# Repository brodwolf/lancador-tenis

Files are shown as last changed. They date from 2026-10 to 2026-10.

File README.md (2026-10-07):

# Lançador de Bolas de Tênis

Máquina de treino portátil, montada em três andares que se separam. Tem duas rodas de velocidade independente para controlar o spin, cabeça com giro e inclinação motorizados, cesto de tela dobrável e baterias Makita 18 V. Projeto aberto, pensado para ser construído com impressão 3D, corte a laser e peças de prateleira.

**Apresentação do projeto:** https://brodwolf.github.io/lancador-tenis/

Demonstração do site

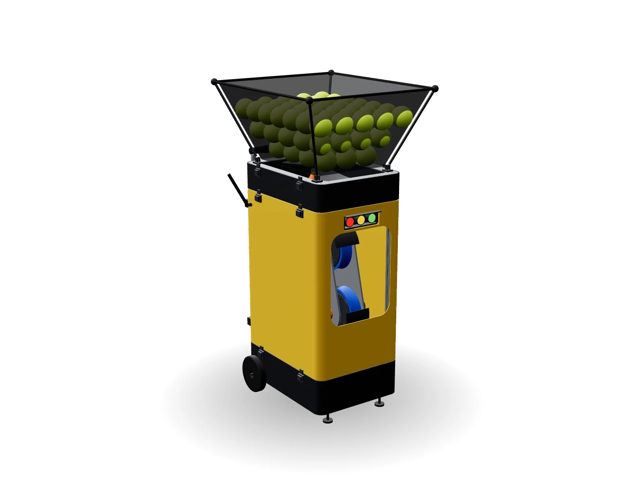
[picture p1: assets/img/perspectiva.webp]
Montagem completa


| Especificação | Valor |
| --- | --- |
| Velocidade da bola | 30–120 km/h |
| Spin | −2.500 rpm (slice) a +3.000 rpm (topspin) |
| Giro / inclinação | ±12,5° / 0° a +30° (máquina no centro da linha de fundo) |
| Cesto | Tela dobrável, ~120 bolas |
| Autonomia | 2,3–4,5 h com 2 baterias Makita 5,0 Ah |
| Dimensões | 32 × 43 cm de base; ~82 cm de altura com o cesto dobrado, 104,5 cm aberto; ~20 kg sem carenagem |
| Carenagem | Material a definir; só STEP de referência |
| Custo estimado | R$ 4,6–8,1 mil, sem baterias e sem carenagem |

## O que tem aqui

| Pasta | Conteúdo |
| --- | --- |
| `index.html`, `assets/` | Página de apresentação: modelo 3D interativo (com e sem carenagem) e simulação na quadra com vento (GitHub Pages) |
| `PROJETO.md` | Memorial técnico em Markdown (sem preços e sem próximos passos) |
| `cad/montagem/` | Montagem em STEP com e sem carenagem (Fusion 360, FreeCAD, Onshape, SolidWorks) |
| `cad/impressao_3d/` | STL e STEP das peças impressas (as `_espelhada` são a cópia do outro lado) |
| `cad/corte_laser/` | DXF das 10 chapas (mm, 1:1) e pranchas em PDF |
| `cad/carenagem/` | STEP dos painéis externos, material a definir |
| `cad/usinagem/` | Eixos em STEP |
| `cad/lista_de_pecas.csv` | Todas as peças com categoria, material e quantidade |
| `cad/lancador.py` | Modelo paramétrico em CadQuery |

A versão anterior, uma estrutura única de 55 × 45 × 120 cm, está no branch [`v1`](../../tree/v1).

## Gerar os arquivos de novo

```
pip install cadquery ezdxf matplotlib
cd cad
python3 exportar.py      # recria STEP, STL, DXF, GLB e a lista de peças em cad/saida/
python3 verificar.py     # confere folgas em 18 posições de giro e inclinação, o caminho da bola e todas as peças entre si
```

Os parâmetros principais ficam no topo de `cad/lancador.py`: tamanho da carenagem, alturas dos andares, linha da bola, rodas e vão, motores e faixas de giro e inclinação.

## Antes de mandar cortar

Os furos de peças compradas seguem cotas de catálogo. Confira com a peça na mão:

- KFL001: 48 mm entre furos, M6
- KFL08: 37 mm entre furos, M4
- lazy susan Ø150: a furação varia por fabricante
- X-mount do motor 4250

Detalhes em `cad/LEIAME.md`.

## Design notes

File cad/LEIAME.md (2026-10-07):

# Lançador de bolas de tênis, versão 2 (compacta, por andares)

Modelo paramétrico feito em CadQuery (Python). Unidades em milímetros.
Origem no chão, no centro da máquina: **x** = largura, **y** = profundidade (+ para a frente), **z** = altura.

A máquina tem três andares que se encaixam com pinos de centragem e travam com fechos de pressão.

- **Controle:** baterias, caixa IP65 e rodas de transporte.
- **Lançador:** giro, inclinação, cabeça, painel traseiro, semáforo e antenas.
- **Alimentador:** disco agitador e rampas.

O cesto de tela dobrável vai por cima dos três.

## Pastas

| Pasta | O que tem | Para quem |
| --- | --- | --- |
| `montagem/lancador_montagem.step` | Montagem completa **com** carenagem | Ver como fica (Fusion 360, FreeCAD, Onshape, SolidWorks) |
| `montagem/lancador_montagem_sem_carenagem.step` | Mesma montagem **sem** carenagem | Montar e conferir a estrutura |
| `corte_laser/` | DXF 1:1 em mm de cada chapa + `pranchas_corte_laser.pdf` com cotas gerais | Serviço de corte a laser |
| `impressao_3d/` | STL (fatiador) e STEP (editar) de cada peça impressa | Sua impressora |
| `usinagem/` | STEP dos eixos | Torno ou barra cortada em casa |
| `carenagem/` | STEP dos painéis externos | Quem for fazer o molde ou os painéis |
| `visualizador/` | GLB da montagem + `pecas.json` (usados pelo site) | Conferir a montagem |
| `lista_de_pecas.csv` | Todas as peças com categoria, material, quantidade e arquivo | Planilha de compras |
| `lancador.py`, `exportar.py`, `verificar.py` | Código-fonte | Mudar cotas e gerar tudo de novo |

## Carenagem: material a definir

A carenagem tem três painéis (um por andar) e a tampa das baterias. **Ela não tem DXF**, porque ainda não se sabe se será molde injetado, termoformada, impressa em partes ou chapa composta.

Os STEP têm 3 mm de parede, cantos de raio 30 e todos os recortes:

- janela da cabeça, semáforo, painel traseiro
- furos das antenas e dos eixos das rodas
- rasgos das abraçadeiras da alça

Servem de base para o molde ou para refazer os painéis no material escolhido. A estrutura não depende da carenagem: a máquina funciona sem ela.

## Antes de mandar cortar as chapas

Os furos de peças compradas seguem cotas de catálogo. **Confira com a peça na mão** antes de enviar os DXF:

- **KFL001** (mancais das rodas): 2 furos M6 a 48 mm. Na placa lateral os furos são de Ø7. A roda de baixo usa furos oblongos, para ajustar o vão.
- **KFL08** (mancais do tilt): 2 furos M4 a 37 mm. No garfo os furos são de Ø4,5.
- **Rolamento lazy susan redondo Ø150**:
  - a furação varia por fabricante; ajuste no `lancador.py` ou fure na montagem
  - base do andar: 4 furos a r 66, girados 45°
  - plataforma: 4 furos a r 60
- **Motor 4250 (X-mount)**: 4 oblongos M3 a r 19, alinhados com a correia, que dão ±3 mm para esticar.
- **Correias**: HTD 3M de 9 mm, fechadas.
  - roda de cima: **600-3M-9**
  - roda de baixo: **288-3M-9**
  - a posição dos motores sai do comprimento da correia; se mudar a correia, mude `CORREIA_A`/`CORREIA_B`
- **NEMA17**: furação padrão de 31 mm, M3.
- **Disco de inércia**: furo em D para o eixo Ø12 com chato (11,1 mm entre a face plana e o lado oposto).
- **Manivela do tilt**: furo em D para o semi-eixo Ø8 com chato de 7 mm.

O laser não faz rosca: rosqueie em casa os furos indicados no documento do projeto.

## Imprimindo

- As peças saem na **posição de montagem**: gire na mesa do fatiador para a melhor orientação.
- Use PETG em tudo, menos a banda das rodas (TPU 95A). Peças expostas ao sol podem ser em ASA.
- `nucleo_roda`: 6 perímetros, 60% gyroid. `banda_roda`: 4 perímetros, 50% gyroid, 20–30 mm/s.
- `rotor_agitador` tem Ø220 mm: cabe em mesa de 235 mm.
- As rampas do alimentador vêm em 4 partes. As duas da frente têm 155 × 256 mm: precisam de mesa de 256 mm ou de um corte a mais.
- Arquivos com `_espelhada` no nome são a cópia do outro lado. Por exemplo, a abraçadeira da alça e o suporte da antena do lado esquerdo.

## Movimentos

| Eixo | Faixa | Acionamento |
| --- | --- | --- |
| Giro (pan) | ±12,5° | NEMA17 com fuso Tr8×8 de 100 mm empurrando um pino a 102 mm do eixo |
| Inclinação (tilt) | 0° a +30° | NEMA17 com fuso Tr8×2 de 100 mm (não volta sozinho), porca com rasgo e manivela de 64 mm |
| Rodas | 2 motores 4250 | Correias HTD 3M, polias de 20 dentes (1:1) |

## Gerar de novo depois de mudar cotas

```
pip install cadquery ezdxf matplotlib
python3 exportar.py      # recria a pasta saida/
python3 verificar.py     # confere as folgas em 18 posições de giro e inclinação e o caminho da bola
```

Os parâmetros principais estão no topo de `lancador.py`: tamanho da carenagem, alturas dos andares, altura da linha da bola, rodas e vão, posição dos motores e faixas de giro e inclinação.

## Simplificações do modelo

São representações simples:

- parafusos, fiação e placas eletrônicas
- servo, tela e baterias
- tela do cesto

Rolamentos e motores têm só as dimensões externas. O fuso dos NEMA17 aparece como uma barra lisa.

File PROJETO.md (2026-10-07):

# Lançador de Bolas de Tênis — Projeto Detalhado

Revisão de 6 de outubro de 2026 · [apresentação com o modelo 3D](https://brodwolf.github.io/lancador-tenis/) · [repositório](https://github.com/brodwolf/lancador-tenis). Esta versão traz o memorial técnico completo; preços, custos e próximos passos ficam de fora.

## 1. Visão geral e decisões de projeto

A v2 tem um objetivo: portabilidade. A máquina ficou no menor tamanho possível (32 × 43 cm de base, ~82 cm de altura com o cesto dobrado), montada em três andares empilhados que se separam sem ferramenta.

Ela trabalha sempre no centro da linha de fundo: dali, ±10° de giro cobrem os cantos do fundo e ±12,5° os da área de saque. A ideia central continua: **só a "cabeça" se move**, e a bola desce por um tubo fixo sobre o eixo do giro. Não mudaram: duas rodas Ø150 independentes com sensor Hall, ESP32‑S3, baterias Makita com diodos ideais, disco agitador e empurrador a servo.

| # | Na v1 | Na v2 | Por quê |
| --- | --- | --- | --- |
| 1 | Uma estrutura alta com os níveis presos nela | Três andares empilhados, centrados por pinos e travados por fechos de pressão | Encolhe e se separa em partes para levar no carro |
| 2 | Perfil 30×30, ~11 m | Perfil 20×20 em cada andar, ~4,1 m | Andares baixos e chapas grossas dão a rigidez; perfis com ~1 kg em vez de 6–9 kg |
| 3 | Giro ±30° | ±12,5° | Basta para a máquina no centro da linha de fundo; menos espaço em volta da cabeça |
| 4 | Inclinação −15° a +15° | 0° a +30° | Lobs e bolas lentas; com a máquina no fundo, ângulo negativo não serve |
| 5 | Linha da bola a 720 mm | 381 mm | Máquina baixa; a altura de saída muda a inclinação necessária só +1 a 2,5° |
| 6 | Motor no eixo da roda, por fora das placas | Correias HTD 3M (1:1), motores entre as placas | Cabeça com 156 mm de largura; a correia isola o motor do choque do disparo |
| 7 | Hopper rígido, 80–100 bolas | Cesto de tela dobrável, ~120 bolas | Dobrado, a altura de transporte cai para ~815 mm |
| 8 | Lazy susan de 300 mm | Lazy susan redondo Ø150 | Giro pequeno e cabeça estreita; cabe na base |
| 9 | Giro por correia GT2 num aro de Ø300 | Fuso Tr8 empurrando um pino a 102 mm do eixo | Sem aro grande; resolução de ~0,0014° |
| 10 | Chave geral náutica; controle só pelo celular | Painel traseiro (tela touch, emergência, liga/desliga com chave anti-faísca), semáforo na frente, antenas de 433 MHz e Wi‑Fi | Usa sem celular; quem está na quadra vê a próxima bola e pausa pelo controle remoto |
| 11 | Telas perfuradas | Carenagem como conjunto separado, material a definir (talvez plástico injetado), só em STEP | A estrutura funciona sem ela; o material decide processo e custo |

Este memorial define dimensões, componentes, ligações e firmware. Os arquivos de CAD (STEP, STL e DXF) seguem estas cotas e estão em [Arquivos do projeto](#arquivos).

## 2. Especificações-alvo

A máquina lança de 30 a 120 km/h com até 3.000 rpm de spin, cobrindo aquecimento, drives, topspin, slice, lobs e bolas rápidas.

| Parâmetro | Alvo | Observação |
| --- | --- | --- |
| Velocidade da bola | 30–120 km/h | Calibrada por fator de eficiência no firmware |
| Spin | −2.500 rpm (slice) a +3.000 rpm (topspin) | Diferença de velocidade entre as rodas |
| RPM máxima da roda | 5.500 rpm | Limite de projeto (roda Ø150 mm) |
| Cadência | 1 bola a cada 1,5–10 s | Só dispara quando as duas rodas estão na RPM alvo |
| Giro horizontal (pan) | ±12,5° | Resolução de ~0,0014° |
| Inclinação (tilt) | 0° a +30° | Resolução de ~0,0006° |
| Altura de lançamento | 381 mm | Igual em qualquer inclinação (o pivô fica na linha da bola) |
| Capacidade do cesto | ~120 bolas | Cesto de tela dobrável, ~40 L |
| Alimentação | 2× Makita 18 V LXT, hot swap | Entrada AC opcional (fase 2) |
| Autonomia | 2,3–4,5 h com 2× 5,0 Ah | Ver cálculo na seção 3 |
| Dimensões em uso | 37,4 × 43 × 104,5 cm | Com as rodas; cesto aberto |
| Dimensões de transporte | 37,4 × ~45,5 × ~81,5 cm | Cesto dobrado, alça recolhida |
| Peso | ~20 kg sem carenagem e sem bolas | Carenagem em ABS: +~3 kg; 120 bolas: ~6,9 kg |
| Controle | Celular (Wi‑Fi), tela touch e controle remoto 433 MHz | Botão de emergência físico |

## 3. Física e dimensionamento

Com rodas de Ø150 mm, a bola mais exigente (110 km/h com 3.000 rpm de topspin) pede 5.443 rpm na roda de cima, por isso o limite de projeto é 5.500 rpm.

### 3.1 Velocidade e spin

A bola sai com a média das velocidades periféricas das rodas, menos as perdas por compressão e escorregamento. O spin vem da diferença entre as rodas.

```math
v_{bola} \approx \eta \cdot \frac{v_{sup} + v_{inf}}{2} \qquad \omega_{bola} \approx k \cdot \frac{v_{sup} - v_{inf}}{g}
```

Para o firmware, a conta é invertida (o usuário escolhe velocidade e spin, a máquina calcula as RPMs):

```math
v_{sup,inf} = \frac{v_{bola}}{\eta} \pm \frac{\omega_{bola} \cdot g}{2k} \qquad RPM = \frac{60 \cdot v_{roda}}{\pi \cdot D_{roda}}
```

Onde g = vão entre as rodas (56 mm), D = diâmetro da roda (150 mm), η ≈ 0,90 e k ≈ 1,0 são fatores de calibração ajustados na prática. Spin positivo = topspin (roda de cima mais rápida).

| Tipo de bola | Velocidade (km/h) | Spin (rpm) | Roda superior (rpm) | Roda inferior (rpm) |
| --- | --- | --- | --- | --- |
| Aquecimento | 40 | 0 | 1.572 | 1.572 |
| Voleio | 60 | 0 | 2.358 | 2.358 |
| Slice | 70 | −1.500 | 2.191 | 3.310 |
| Drive plano | 80 | 0 | 3.143 | 3.143 |
| Topspin médio | 80 | +1.500 | 3.704 | 2.583 |
| Topspin pesado | 90 | +2.500 | 4.470 | 2.604 |
| Bola rápida plana | 120 | 0 | 4.716 | 4.716 |
| Limite de projeto | 110 | +3.000 | 5.443 | 3.203 |

### 3.2 Inércia da roda e consistência

A bola a 120 km/h leva ~32 J de energia cinética (m = 57,5 g). Cada roda cede ~15–25 J por disparo, contando as perdas.

Cada roda tem I ≈ 2,6 × 10⁻³ kg·m² (núcleo impresso + 2 discos de aço + banda de TPU, ~1 kg; a polia soma pouco). A 3.500 rpm ela guarda ~175 J, então cai só 5–7% de RPM por disparo. O firmware espera a RPM voltar (< 0,5 s) antes do próximo disparo.

### 3.3 Motores e correias

- **KV:** para chegar a 5.500 rpm com carga e bateria no fim (16 V), KV ≥ 5.500 / (0,85 × 16) ≈ 400. Faixa recomendada: **400–500 KV**.
- **Torque de partida:** acelerar de 0 a 3.500 rpm em 5 s exige ~0,19 N·m (~9 A por motor). Rampas mais rápidas somam corrente; o firmware limita a rampa para manter o total abaixo de 25 A.
- **Recuperação:** repor 20 J em 0,5 s = ~40 W por motor, uma fração da capacidade.
- **Classe:** outrunner 4250 (Ø42 × 50 mm), ≥ 500 W: é o tamanho que cabe entre as placas. A potência média é baixa; a folga é térmica e de durabilidade.
- **Transmissão:** correia HTD 3M 1:1 (RPM do motor = RPM da roda). Ela só leva o torque do motor (~0,2–0,4 N·m na aceleração); o choque do disparo fica com a inércia da roda e os mancais.

### 3.4 Autonomia

Uma Makita 18 V 5,0 Ah tem 90 Wh, dos quais ~80 Wh são úteis até 15 V. Duas baterias dão ~160 Wh.

| Situação | Consumo médio | Autonomia (2× 5,0 Ah) |
| --- | --- | --- |
| Rodas girando, sem disparar | ~25 W | ~6 h |
| Treino típico (80 km/h, 1 bola a cada 4 s) | ~35–45 W | ~3,5–4,5 h |
| Treino pesado (120 km/h, 1 bola a cada 2 s) | ~60–70 W | ~2,3–2,7 h |

São estimativas. O firmware mede a tensão de cada bateria; com um sensor de corrente opcional (INA226) você mede o consumo real.

### 3.5 Trajetória e simulação na quadra

A aba **Quadra**, ao lado do modelo 3D, mostra onde a bola quica. A máquina fica no centro, com a frente da carenagem encostada na linha de fundo (ou na linha de saque), e a bola sai logo depois do ponto de contato das rodas, a ~0,38 m do chão com a cabeça a 0° (~0,51 m a +30°), na direção dada pelo giro e pela inclinação. Também dá para tocar num ponto da quadra adversária: a página calcula o giro e a inclinação para a bola quicar ali. Há ainda vento, com velocidade de 0 a 40 km/h e direção; com a mira ativa, a página corrige giro e inclinação para compensar.

[Abrir a simulação na quadra](https://brodwolf.github.io/lancador-tenis/#quadra)

Em voo, a bola sofre o peso, o arrasto do ar e a força de Magnus causada pelo spin. As duas forças do ar dependem da velocidade da bola **em relação ao ar**, v_r = v − v_vento:

```math
m\,\frac{d\vec v}{dt} = m\,\vec g \;-\; \tfrac{1}{2}\,\rho A\,C_D\,|\vec v_r|\,\vec v_r \;+\; \tfrac{1}{2}\,\rho A\,C_L\,|\vec v_r|^2\,(\hat\omega \times \hat v_r) \qquad \vec v_r = \vec v - \vec v_{vento}
```

Os coeficientes vêm do ajuste empírico de Goodwill, Chin e Haake (2004), medido em túnel de vento com bolas girando, em função da razão entre a velocidade da bola em relação ao ar, v, e a velocidade periférica do spin, v_s = r·ω:

```math
C_D = 0{,}55 + \frac{1}{\left[\,22{,}5 + 4{,}2\,(v/v_s)^{2{,}5}\right]^{0{,}4}} \qquad C_L = \frac{1}{2 + v/v_s}
```

No quique, a velocidade vertical volta multiplicada pelo coeficiente de restituição e, e o atrito freia o ponto de contato até a bola parar de escorregar e começar a rolar (modelo de R. Cross). O mesmo atrito muda o spin: o topspin sai do quique mais rápido para a frente, e o slice freia e fica baixo.

```math
v_y' = -e\,v_y \qquad J_t = \min\!\left(\mu\,(1+e)\,|v_y|,\; \frac{\alpha}{1+\alpha}\,|u_c|\right) \qquad I = \alpha\, m\, r^2
```

Onde u_c é a velocidade do ponto de contato com o chão e J_t é o impulso de atrito por unidade de massa. A trajetória é integrada por Runge‑Kutta de 4ª ordem com passo de 2 ms.

| Parâmetro | Valor usado |
| --- | --- |
| Bola | 57 g, Ø67 mm, α = 0,55 |
| Ar | ρ = 1,21 kg/m³ (nível do mar, 20 °C); vento opcional de 0 a 40 km/h, em qualquer direção, uniforme |
| Quadra rápida | e = 0,78, μ = 0,65 |
| Saibro | e = 0,80, μ = 0,80 |
| Rede | 0,914 m no centro, 1,07 m nos postes |
| Bola dentro | 1º quique na quadra de simples do adversário; a linha conta como dentro |

Inclinação que põe o 1º quique dentro e onde ele cai (distância depois da rede), em quadra rápida, com a máquina no centro e inclinação de 0° a +30°:

| Bola | Velocidade e spin | Da linha de saque | Da linha de fundo |
| --- | --- | --- | --- |
| Aquecimento | 40 km/h, sem spin | +22° a +30° → 2,2–3,6 m | não cai dentro |
| Voleio | 60 km/h, sem spin | +11,9° a +27,7° → 4,9–11,9 m | +17,7° a +30° → 2,5–7,0 m |
| Drive plano | 80 km/h, sem spin | +8,8° a +12,9° → 8,0–11,8 m | +10,8° a +20,3° → 4,4–11,9 m |
| Topspin médio | 80 km/h, +1.500 rpm | +10° a +18° → 6,3–11,8 m | +13,4° a +30° → 3,4–11,6 m |
| Slice | 70 km/h, −1.500 rpm | +8,9° a +15,6° → 7,1–11,9 m | +11,5° a +30° → 3,7–11,6 m |
| Topspin pesado | 90 km/h, +2.500 rpm | +9,5° a +15,8° → 6,9–11,9 m | +12,3° a +25,4° → 3,8–11,8 m |
| Bola rápida plana | 120 km/h, sem spin | não cai dentro | +6,2° a +7,8° → 8,9–11,9 m |

**O que isso diz sobre o projeto:** da linha de fundo, onde a máquina fica, a faixa de 0° a +30° põe drive, topspin e slice em qualquer profundidade, de ~3,5–4,5 m da rede até a linha de fundo. O voleio de 60 km/h chega a ~7 m da rede e a bola rápida de 120 km/h só cai no fundo (~9–12 m). O aquecimento a 40 km/h não chega à quadra adversária saindo da linha de fundo: para ele, ponha a máquina na linha de saque. "Não cai dentro" quer dizer que, naquela posição, a bola ou bate na rede ou sai longa.

Quanto o vento desloca o quique: máquina na linha de fundo, inclinação ajustada para a bola quicar a 8 m da rede sem vento; "da esquerda" é o vento que vem da esquerda de quem está atrás da máquina.

| Bola | Inclinação | 10 km/h a favor | 10 km/h contra | 10 km/h da esquerda | 20 km/h a favor | 20 km/h contra | 20 km/h da esquerda |
| --- | --- | --- | --- | --- | --- | --- | --- |
| Drive plano (80 km/h, sem spin) | +14,9° | 9,2 m | 6,8 m | 0,6 m para a direita | 10,3 m | 5,5 m | 1,3 m para a direita |
| Topspin médio (80 km/h, +1.500 rpm) | +21° | 9,9 m | 6,2 m | 0,9 m para a direita | 11,9 m | 4,4 m | 1,8 m para a direita |
| Slice (70 km/h, −1.500 rpm) | +18,6° | 9,1 m | 6,6 m | 1,0 m para a direita | 10,0 m | 5,0 m | 2,1 m para a direita |

Um vento de 20 km/h contra encurta o topspin médio de 8 m para 4,4 m da rede; a favor, alonga para 11,9 m. De lado, os mesmos 20 km/h desviam a bola 1,3–2,1 m; o slice, mais lento e mais tempo no ar, é o que mais deriva.

São aproximações. Bola gasta, altitude (em São Paulo o ar é ~7% menos denso, e a bola vai um pouco mais longe), rajadas (o simulador usa vento constante e igual em toda a quadra) e os valores reais de η e k mudam o quique em alguns decímetros. A calibração do protótipo (seção 19) acerta os números.

## 4. Arquitetura e cotas

A linha da bola fica a 381 mm do chão, e o pivô do tilt fica nela, exatamente sobre o eixo do giro, 116 mm atrás do centro da máquina.

Vista lateral esquemática com as cotas de altura

Como o recuo do disparo age ao longo da linha da bola, e essa linha cruza os dois eixos, o tiro não gera torque que desvie a mira. O tubo de queda fica parado enquanto a cabeça gira e inclina embaixo dele.

**Referência de cotas:** z = altura a partir do chão; x = largura (0 no centro); y = profundidade (positivo para a frente, 0 no centro). Na cabeça: u = para a frente ao longo da linha da bola, v = para cima, origem no pivô.

- **Eixo do giro:** x = 0, y = −116 mm. Sobre ele ficam o furo de saída, o tubo de queda (z 466–696) e o pivô do tilt (z 381, 205 mm acima da plataforma).
- **Nip:** 215 mm à frente do pivô, na linha da bola.

## 5. Estrutura em andares

Três andares de chapa de alumínio e perfil 20×20 canal 6, empilhados e centrados por pinos; todas as chapas internas medem 312 × 422 mm.

### 5.1 Andares

| Andar | Base | Postes 20×20 | Topo | O que leva |
| --- | --- | --- | --- | --- |
| Controle | Piso Al 3 mm em z = 45 | 4 × 112 mm | z = 160 | Baterias, eletrônica, rodas de transporte, pés |
| Lançador | Al 4 mm em z = 160 | 4 × 536 mm + quadro do topo | z = 700 | Giro, garfo, cabeça, atuadores, painel traseiro, semáforo, antenas, alça |
| Alimentador | Al 3 mm em z = 700 | 4 × 79 mm | Aro Al 3 mm em z = 785 | Disco agitador, rampas, tubo de queda |
| Cesto | Aro do alimentador | 4 varetas Ø8 | z = 1.045 (dobrado ~815) | ~120 bolas |

### 5.2 Lista de corte (perfil 20×20 canal 6)

| Peça | Qtd | Comprimento (mm) |
| --- | --- | --- |
| Poste do andar de controle | 4 | 112 |
| Poste do andar do lançador | 4 | 536 |
| Poste do alimentador | 4 | 79 |
| Travessa lateral do quadro do topo | 2 | 360 |
| Travessa frente/trás do quadro do topo | 2 | 250 |
| **Total** | **16** | **~4,1 m** |

Peça os cortes no esquadro (±0,3 mm) e rosqueie M5 o furo central nas duas pontas de cada poste.

### 5.3 Chapas e fixação

- **Postes:** centros a ±135 mm (x) e ±190 mm (y), cada um preso nas chapas por um parafuso M5 no furo central. Nas bases do lançador e do alimentador, que apoiam sobre os postes de baixo, use parafuso escareado.
- **Quadro do topo do lançador:** travessas de 360 e 250 mm entre os postes, em z = 680–700, com 4 cantoneiras 20×20. O alimentador apoia nele.

### 5.4 União entre andares

- **Centragem:** 2 pinos em diagonal por junta. Controle → lançador: pinos impressos em blocos presos na face dos postes, que entram em furos Ø8,4 da base do lançador. Lançador → alimentador: pinos-guia Ø10 presos por M4 + porca-T no canal de cima das travessas.
- **Travamento:** 8 fechos de pressão inox, 4 por junta (2 de cada lado), na carenagem: controle/lançador e lançador/alimentador. O cesto só assenta no aro do topo. Sem carenagem, os pinos centram e o peso segura; para transportar montada, prenda os fechos em chapinhas nos postes ou passe uma cinta.
- **Cabos:** 3 suportes impressos de conectores (2 na junta de baixo, 1 na de cima). Desconecte antes de separar os andares.

## 6. Módulo de lançamento

Duas rodas de Ø150 mm, uma sobre a outra com vão de 56 mm, cada uma no seu eixo de Ø12 mm com dois mancais e acionada por um motor brushless através de uma correia HTD.

**Referência da cabeça:** origem no pivô do tilt (sobre o eixo do giro); u para a frente ao longo da linha da bola, v para cima. O nip fica em u = 215 mm, v = 0. Os centros das rodas ficam em (215, +103) e (215, −103).

### 6.1 Geometria

| Item | Valor | Nota |
| --- | --- | --- |
| Diâmetro externo da roda | 150 mm | Com banda de rodagem |
| Largura da roda | 40 mm | Perfil côncavo, centraliza a bola |
| Vão entre rodas | 56 mm (ajuste 52–60) | Comprime a bola ~11 mm no total |
| Distância entre eixos | 206 mm | 150 + 56 |
| Distância pivô → nip | 215 mm | Cabem o berço e os dois motores entre o pivô e as rodas |
| Distância interna entre placas | 90 mm | Roda, colares, mancais KFL001 e motores |
| Largura da cabeça | 156 mm | Placas de 6 mm (347 × 310) + tampas das correias; 4 espaçadores M5 × 90 |

### 6.2 Construção da roda

1. **Núcleo** impresso em PETG (ou ASA/PA‑CF): Ø134 × 32 mm, 6 perímetros, 60% gyroid, furo central Ø12,2 mm.
2. **Dois discos de aço** 3 mm, Ø120 mm (corte a laser), um em cada face: dão inércia e uma espinha metálica à roda.
3. **Seis parafusos M4** passantes prendem discos e núcleo; os discos têm **furo em D** que encaixa no chato do eixo e transmite o torque direto, sem cubo.
4. **Banda de rodagem** em TPU 95A impressa: Ø134 → Ø150, 40 mm de largura, com chavetas internas que encaixam em ranhuras do núcleo, mais cola PU. As chavetas impedem que ela solte com a força centrífuga.
5. **Polia** HTD 3M de 20 dentes (furo 12 mm) na ponta do eixo, por fora da placa; parafuso sem cabeça sobre o chato, com trava-rosca.
6. **Balanceamento estático:** apoie o eixo sobre duas réguas retas niveladas; a roda deve parar em posições aleatórias. Corrija com arruelas M3 coladas no lado leve.

### 6.3 Eixos, mancais, correias e motores

- **Eixo:** aço Ø12 h6 × 140 mm, com um chato de 1 mm em todo o comprimento. Pode ser barra retificada cortada ou peça usinada.
- **Mancais:** 4× KFL001 (Ø12, 2 furos M6 a 48 mm), por dentro das placas. Confirme rotação limite ≥ 6.000 rpm. Os furos da roda de baixo são **oblongos (±4 mm)** para ajustar o vão; colares Ø12 dos dois lados da roda.
- **Motores:** 2× outrunner 4250, 400–500 KV, com **eixo invertido** (em muitos modelos basta soltar o anel de trava e empurrar o eixo), cada um por dentro de uma placa com o eixo atravessando-a até a polia. Roda de cima: placa +x, em (u 51,7; v −112); roda de baixo: placa −x, em (u 101,4; v −112).
- **Correias:** HTD 3M de 9 mm, fechadas: **600‑3M‑9** na roda de cima e **288‑3M‑9** na de baixo. A posição dos motores sai do comprimento da correia.
- **Tensionamento:** oblongos M3 no X‑mount (±3 mm). Estique até a correia ceder ~1/64 do vão com força leve: ~4 mm na de cima, ~2 mm na de baixo.
- **Tampas das correias:** impressas, presas por 2 espaçadores M3 cada, dentro do laço da correia.

### 6.4 Sensor de RPM

No lado oposto à polia, o eixo sobra além da placa. Ali entra um disco impresso Ø40 com 2 ímãs Ø6 × 3 mm opostos (2 pulsos por volta). Um módulo Hall A3144 fica a 2–4 mm, num suporte impresso.

### 6.5 Guia da bola e proteções

- **Guia:** dois trilhos de alumínio Ø8 × 215 mm do berço até perto do nip. A bola chega centrada e com velocidade repetível.
- **Carenagens das rodas:** duas peças impressas (PETG ou ASA) que cobrem cada roda por cima, por trás e pelos lados.

## 7. Módulo de inclinação (tilt)

A cabeça pivota sobre dois semi-eixos de Ø8 mm, e um NEMA17 com fuso Tr8×2 integrado, ligado a uma manivela, a inclina de 0° a +30° em ~1,7 s.

### 7.1 Pivô

- **Garfo:** duas chapas de alumínio 6061 de 6 mm, presas na plataforma por 2 cantoneiras 40 × 40 × 3; pivô 205 mm acima da plataforma.
- **Semi-eixos:** o berço fica no pivô, e um eixo inteiro bloquearia a bola. Lado +x: Ø8 × 50 mm; lado −x: Ø8 × 65 mm com chato para a manivela. 4 colares Ø8.
- **Mancais:** 2× KFL08 (flange, Ø8, 2 furos M4 a 37 mm) nas chapas do garfo.

### 7.2 Atuador

| Item | Valor |
| --- | --- |
| Motor | NEMA17 com fuso trapezoidal Tr8×2 integrado (passo de 2 mm), 100 mm, porca de latão |
| Montagem | Deitado ao longo da linha da bola, preso no garfo −x por suporte impresso |
| Transmissão | Porca num bloco impresso com rasgo, onde entra o pino da manivela (parafuso de ombro Ø6, M5) |
| Manivela | Alumínio 6 mm, raio 64 mm, furo em D no semi-eixo −x |
| Curso da porca | ~33 mm para 0–30° (~16,5 voltas) |
| Resolução | 0,000625 mm por micropasso (1/16) = ~0,0006° |
| Tempo de 0° a +30° | ~1,7 s a 600 rpm |

A 15° a manivela aponta para baixo: a ponta anda quase só ao longo do fuso e o curso fica quase linear com o ângulo.

A cabeça tem ~6 kg e é pesada na frente (~8–10 N·m em torno do pivô), o que dá ~130–150 N na porca. Com passo de 2 mm isso pede só ~0,13 N·m no motor, um terço do torque de um NEMA17 de 40 mm. Por isso o tilt usa o fuso de 2 mm e não o de 8 mm: com 8 mm o motor ficaria no limite e a cabeça cairia sem corrente.

### 7.3 Referência e limites

- **Referência:** no limite de 0°, por microchave ou pela detecção de travamento do TMC2209 (StallGuard). Na partida, o tilt desce até a referência e vai para a posição pedida.
- **Limites:** 0° a +30° no firmware; em toda a faixa, a menor folga entre cabeça e garfo é 2,7 mm.
- **Repouso:** o fuso de 2 mm por volta não é reversível: sem corrente, a cabeça fica onde está. Um batente de borracha no garfo, logo abaixo de 0°, protege contra erro de referência.
- **Calibração do zero:** inclinômetro do celular sobre a placa lateral; grave o desvio no firmware.

## 8. Módulo de giro (pan)

A plataforma giratória roda sobre um lazy susan redondo de Ø150; um NEMA17 com fuso Tr8 move um bloco com rasgo que empurra um pino a 102 mm do eixo. Os ±22 mm de curso dão ±12,5°.

### 8.1 Rolamento e placas

- **Rolamento:** lazy susan redondo Ø150 (6"), centrado no eixo do giro. A furação varia por fabricante: no DXF são 4 furos a r 66 (girados 45°) na base e 4 a r 60 na plataforma; confira com a peça na mão.
- **Plataforma giratória:** alumínio 4 mm, 197 × 156 mm (raio de até 84 mm, mais o braço do pino), furo central Ø40; o garfo é preso nela (seção 7.1).

### 8.2 Transmissão

| Item | Valor |
| --- | --- |
| Motor | NEMA17 com fuso Tr8×8 integrado de 100 mm, deitado ao longo de y no lado +x, em suporte impresso em L |
| Ponta do fuso | Mancal impresso com rolamento 608 |
| Pino | Parafuso de ombro M6 no braço da plataforma, a 102 mm do eixo; entra no rasgo do bloco-porca |
| Curso | ±22 mm para ±12,5° |
| Resolução | 0,0025 mm / 102 mm = ~0,0014° |
| Velocidade | 300 rpm no motor = 40 mm/s = ~22°/s; de um lado ao outro em ~1,1 s |

O fuso não escorrega, e o recuo do disparo quase não gera torque no eixo do giro, porque a linha da bola passa por ele. Se houver folga visível na porca, use uma porca anti-folga (com mola).

### 8.3 Cabos, referência e limites

- **Cabos:** pelo furo central Ø40 da base, com um laço de ~15–20 cm preso com abraçadeiras. Com ±12,5°, não precisa de anel coletor.
- **Fim de curso:** microchave na base. Na partida, o giro vai até ela e volta ao centro.
- **Limites:** ±12,5° no firmware. A menor folga é 2,0 mm, entre a parte que gira e o motor do giro: não force além dos limites nem com a mão.

## 9. Alimentador e cesto

Um disco com 4 bolsões, girado por um NEMA17, solta exatamente uma bola por comando num tubo fixo sobre o eixo do giro; a bola cai no berço da cabeça e um servo a empurra para as rodas.

### 9.1 Cesto dobrável

- **Tamanho:** base 268 × 338 mm, topo 460 × 540 mm, 246 mm de altura: ~40 L, ~120 bolas soltas.
- **Varetas:** 4 varetas de alumínio Ø8 inclinadas, com a ponta de baixo amassada e furada, giram em dobradiças impressas no aro do topo (pino M3). O aro de cima tem 4 varetas Ø8 unidas por 4 cantos impressos.
- **Tela:** PVC/poliéster em 4 painéis costurados, presos nas varetas.
- **Dobrado:** as varetas deitam sobre o aro e a tela fica por cima; a máquina fica com ~815 mm de altura.

### 9.2 Andar do alimentador

- **Base:** alumínio 3 mm em z = 700 (teto do andar do lançador); postes de 79 mm; aro do topo em z = 785, onde assenta o cesto.
- **Furo de saída:** Ø76 exatamente sobre o eixo do giro.
- **Rampas:** 4 peças impressas com 15° de queda levam as bolas até o disco.

### 9.3 Disco agitador

| Item | Valor |
| --- | --- |
| Disco | PETG, Ø220 com cúpula, 4 bolsões Ø74 a 70 mm do centro |
| Posição | Centro 70 mm à frente do eixo do giro (y = −46): um bolsão por vez fica sobre o furo de saída |
| Motor | NEMA17 curto (~34 mm) pendurado embaixo da base; o eixo atravessa a base até o rotor |
| Passo | 90° por bola = 800 micropassos (1/16) |
| Capuz | Sobre o furo de saída: só a bola do bolsão passa por baixo |
| Deslizante | Folha de PTFE ou UHMW 0,5 mm sob o disco |
| Antitravamento | Sem bola detectada no tubo → recua 30° e tenta de novo; 4 bolsões vazios seguidos → aviso "cesto vazio" |

### 9.4 Tubo de queda e funil

- Tubo de PVC esgoto DN75 (interno ~72 mm), 230 mm, preso na base do alimentador por um flange impresso.
- Termina a 466 mm do chão, 85 mm acima da linha da bola: fica acima do funil da cabeça em qualquer inclinação de 0 a 30°.
- O funil da cabeça tem boca de 84 × 140 mm (mais comprida para a frente, porque recua quando a cabeça inclina) e afunila até Ø78 mm.
- Sensor infravermelho E18‑D80NK atravessando o tubo: confirma que a bola caiu.

### 9.5 Berço e empurrador

- **Berço:** peça impressa no pivô, entre os dois trilhos; segura a bola em qualquer inclinação.
- **Empurrador:** servo rápido de 20–25 kg·cm (tamanho padrão, engrenagens metálicas, ≤ 0,07 s/60°), eixo em u = −45, v = −82. O braço impresso (~73 mm, ponta de TPU) passa por um rasgo no berço e lança a bola pelos trilhos; ela entra sempre com a mesma velocidade.
- **Até as rodas:** elas pegam a bola ~180 mm à frente do berço. A +30°, a bola sobe ~90 mm nesse caminho e precisa sair do empurrador a ~1,5 m/s. Um DS3225 comum (~0,13 s/60°) dá ~0,6 m/s na ponta do braço, o que basta só até ~15°; por isso o servo rápido. Confira no protótipo que a bola chega às rodas em toda a faixa (teste 6 da seção 19); se não chegar, alongue o braço.

### 9.6 Ciclo de um disparo

1. Disco gira 90° → bola cai pelo tubo → sensor do tubo confirma.
2. Firmware espera: RPM das duas rodas dentro de ±1,5% por 300 ms, giro e tilt parados na posição.
3. Semáforo amarelo piscando: contagem para a próxima bola.
4. Semáforo verde, servo empurra → bola sai → servo volta.
5. Próxima bola é liberada (o tempo mínimo do ciclo é ~1,5 s).

## 10. Base, transporte e carenagem

O andar de controle é a base; para mover, inclina-se a máquina para trás e puxa-se pela alça, como uma mala de rodinhas.

### 10.1 Base

- **Piso:** alumínio 3 mm a 45 mm do chão; postes de 112 mm.
- **Baterias:** 2 Makita deitadas em berços impressos na metade de trás; saem por trás, pela tampa das baterias. Caixa IP65 na metade da frente; diodos ideais e chave anti-faísca ao lado das baterias.
- **Rodas de transporte:** 2 rodas de patins inline Ø125 × 24 com rolamentos 608, por fora da largura (374 mm no total), 65 mm à frente da traseira. Eixo Ø8 × 60 (pode ser parafuso de ombro) em suportes de alumínio 4 mm.
- **Pés:** 2 pés de borracha M8 reguláveis na frente, para nivelar.

### 10.2 Alça e transporte

- **Alça:** telescópica de mala (2 tubos), presa nos postes de trás por 4 abraçadeiras impressas. Recolhida, o pegador fica a ~815 mm.
- **Para puxar:** incline ~30° para trás. Acima de ~45°, a borda de trás do piso encosta no chão.
- **Transporte:** cesto dobrado e alça recolhida: 374 × ~455 × ~815 mm, ~20 kg (~23 kg com carenagem de 3 mm em ABS). Para carregar em partes, desconecte os conectores entre andares, abra os fechos e tire o alimentador (com o cesto) e depois o andar do lançador.

### 10.3 Carenagem (material a definir)

- **O que é:** um conjunto separado de 3 painéis (um por andar) e a tampa das baterias, por fora dos postes. O material ainda não foi definido; plástico injetado está sendo considerado (opções na seção 16.4).
- **O que o projeto entrega:** só STEP de referência, sem DXF, com parede de 3 mm, cantos verticais R30 e todos os recortes: janela da cabeça (232 × 297 mm), semáforo, painel traseiro, furos das antenas, eixos das rodas de transporte, rasgos das abraçadeiras da alça e tampa das baterias. A menor folga até a cabeça é 6,9 mm.
- **Sem carenagem:** a máquina funciona igual. As proteções mínimas são as carenagens impressas das rodas e as tampas das correias (seção 20).

## 11. Sistema de potência

Duas baterias Makita alimentam um barramento de 15–21 V através de diodos ideais; uma chave eletrônica anti-faísca, comandada pelo botão liga/desliga do painel traseiro, liga e desliga tudo, e um relé comandado pelo botão de emergência corta os motores das rodas.

Caminho da energia das baterias até cada carga

Cada fonte entra por seu próprio diodo ideal, e só o ramo das rodas passa pelo relé comandado pelo botão de emergência.

### 11.1 Baterias e hot swap

- **Baterias:** Makita LXT 18 V, 5,0 Ah (BL1850B) ou 6,0 Ah (BL1860B), que dá ~20% mais autonomia no mesmo espaço.
- **Soquetes:** 2 adaptadores de bateria Makita 18 V com fios 12 AWG. Cada um passa por um **fusível de 30 A** e por um **módulo diodo ideal** (≥ 30 A) antes da chave.
- **Por que diodo ideal:** a bateria com tensão mais alta alimenta, e não passa corrente de uma bateria para a outra. Dá para tirar uma bateria com a máquina ligada.
- **Corte por subtensão no firmware:** adaptadores simples não têm proteção contra descarga profunda; a [PartsBuilt](https://partsbuilt.com/makita-18v-battery-adapter) vende adaptadores com uma placa extra só para isso. Aqui, o ESP32 mede cada bateria e para de disparar a 15,5 V; abaixo de 15,0 V desliga as rodas.

### 11.2 Entrada AC (opcional, fase 2)

- **Caminho:** tomada IEC C14 com fusível e chave → fonte fechada **Mean Well LRS‑350‑24** → terceiro diodo ideal → barramento. A v2 não tem espaço para a fonte (215 × 115 × 30 mm): monte-a numa caixa externa, ligada à máquina por XT60.
- **Ajuste:** a saída dessa fonte vai de 21,6 a 28,8 V ([folha de dados Mean Well](https://www.meanwell.com/Upload/PDF/LRS-350/LRS-350-SPEC.PDF)). Ajuste no mínimo (21,6 V): fica acima da bateria cheia, então a fonte alimenta e as baterias descansam. Ela **não** carrega as baterias.
- **Chave de tensão de entrada:** 90–132 ou 180–264 VAC, escolhida por chave na fonte. Em 127 V use 115; em 220 V use 230. Posição errada queima a fonte.
- **Limite de 350 W:** a fonte aguenta 150% de pico por até 1 s. Com AC, o firmware alonga a rampa de partida das rodas.
- **Aterramento:** terra da tomada na caixa da fonte, bornes cobertos; peça a um eletricista para revisar antes de ligar.

### 11.3 Distribuição, proteção e bitolas

| Circuito | Proteção | Fio | Observação |
| --- | --- | --- | --- |
| Bateria A/B → diodo ideal | Fusível lâmina 30 A | 12 AWG (4 mm²) | Porta-fusível junto do soquete |
| Diodos → chave anti-faísca → barramento | Chave eletrônica ≥ 60 A | 12 AWG | Comandada pelo botão liga/desliga |
| Relé K1 → ESC superior | Fusível 25 A | 14 AWG (2,5 mm²) |  |
| Relé K1 → ESC inferior | Fusível 25 A | 14 AWG |  |
| ESC → motor | — | 14 AWG silicone | Conector MT60 (3 vias) entre andares |
| Drivers TMC2209 (×3) | Fusível 5 A | 18 AWG (1 mm²) | Capacitor 1.000 µF / 35 V no barramento dos drivers |
| Buck 5 V / 3 A | Fusível 3 A | 20 AWG | ESP32, tela touch, sensores, receptor 433 MHz e semáforo |
| Buck 6 V / 5 A (XL4015) | Fusível 5 A | 18 AWG | Servo do empurrador |
| Buck 12 V / 1 A | Fusível 2 A | 22 AWG | Bobina do relé K1, LED do botão liga/desliga e ventoinha da caixa, se usar |
| Sinais | — | 24–26 AWG | Motores de passo: cabo 4 × 22 AWG; antenas: coaxial com SMA |

### 11.4 Parada e intertravamentos

- **Liga/desliga:** botão 22 mm com retenção e anel de LED no painel traseiro; comanda a chave anti-faísca, que corta toda a máquina. A chave é eletrônica: para mexer na fiação, tire as baterias.
- **Botão de emergência** tipo cogumelo, 1NF + 1NA, no painel traseiro. O contato NF alimenta a bobina do **relé K1 (40 A)** dos ESCs; o NA avisa o ESP32.
- **Desarme por software:** o ESP32 também abre K1 por um MOSFET (falha de sensor, perda do app em treino iniciado pelo app, bateria baixa).
- **Inércia:** sem energia, as rodas ainda giram 10–30 s. Na parada normal o firmware zera o acelerador com freio do ESC ligado antes de abrir o relé.
- **Diodo de roda livre** (1N4007) na bobina de K1.

## 12. Eletrônica de controle

Um ESP32‑S3 comanda 2 ESCs, 3 drivers TMC2209, 1 servo e o semáforo, lê os sensores, as 2 baterias e o receptor de 433 MHz e conversa com a tela touch por UART, usando 26 GPIOs; tudo fica numa caixa IP65 no andar de controle.

### 12.1 Componentes

- **Controlador:** ESP32‑S3‑DevKitC‑1U‑N8R8 (conector U.FL para antena externa). Os pinos 35–37 ficam com a PSRAM; 19 e 20 são o USB nativo.
- **ESCs:** 2× ESC brushless 60–80 A, 2–6S. Ligue só sinal e GND (o fio vermelho do BEC fica isolado). Configure: freio ligado, partida suave, corte de bateria no mínimo (quem corta é o firmware).
- **Drivers:** 3× TMC2209 em modo UART num único fio, endereços por MS1/MS2: giro = 0, tilt = 1, agitador = 2. Correntes: giro 0,8 A RMS, tilt 0,8 A, agitador 0,6 A.
- **Sensores:** 2× Hall A3144 (pull-up 10 kΩ para 3,3 V + 100 nF); 1× E18‑D80NK no tubo (5 V, saída NPN com pull-up para 3,3 V); microchave do giro ligada como NF para GND (fio rompido = fim de curso acionado). O tilt usa o DIAG do TMC2209 (StallGuard) ou uma segunda microchave.
- **Receptor 433 MHz:** RXB6 (5 V) com controle de chaveiro de 4 botões (código fixo, tipo EV1527); saída por divisor 10 kΩ / 20 kΩ. A antena SMA vai soldada no pino ANT por cabo coaxial.
- **Tela touch:** placa com ESP32‑S3 próprio e tela IPS 3,5", alimentada em 5 V, ligada ao controlador por UART (115.200 bps).
- **Semáforo:** 12 LEDs WS2812B (3 células de 4) num pino, com 330 Ω em série; se piscar errado, use um 74AHCT125 como conversor de nível.
- **Divisores das baterias:** 100 kΩ / 12 kΩ + 100 nF, medidos antes dos diodos ideais (21,6 V → 2,3 V no ADC).
- **Relé K1:** acionado por módulo MOSFET de nível lógico (AO3400 ou IRLZ44N) no lado de GND da bobina.

### 12.2 Pinagem do ESP32‑S3

| GPIO | Função | Direção | Nota |
| --- | --- | --- | --- |
| 1 | Tensão bateria A | ADC | ADC1 (funciona com Wi‑Fi ligado) |
| 2 | Tensão bateria B | ADC | ADC1 |
| 3 | Receptor 433 MHz | Entrada | Interrupção, decodificado no firmware |
| 4 | ESC roda superior | Saída PWM | 50 Hz, 1.000–2.000 µs |
| 5 | ESC roda inferior | Saída PWM | 50 Hz, 1.000–2.000 µs |
| 6 | Hall roda superior | Entrada | Contador de pulsos (PCNT) |
| 7 | Hall roda inferior | Entrada | Contador de pulsos (PCNT) |
| 8 | STEP agitador | Saída | Direção invertida via UART |
| 9 | Buzzer | Saída | Bip antes de cada treino |
| 10 | ENABLE drivers | Saída | Comum aos 3, ativo em nível baixo |
| 11 | UART drivers | Bidirecional | 1 kΩ em série até o PDN\_UART |
| 12 | Servo empurrador | Saída PWM | 50 Hz |
| 13 | Fim de curso giro | Entrada | Pull-up interno, NF |
| 14 | Referência do tilt | Entrada | DIAG do TMC2209 ou microchave NF |
| 15 | STEP giro | Saída |  |
| 16 | DIR giro | Saída |  |
| 17 | STEP tilt | Saída |  |
| 18 | DIR tilt | Saída |  |
| 21 | Sensor bola no tubo | Entrada |  |
| 38 | Semáforo WS2812B | Saída | 330 Ω em série |
| 39 | UART da tela (TX) | Saída | 115.200 bps |
| 40 | UART da tela (RX) | Entrada |  |
| 41 | Estado do botão de emergência | Entrada | Contato NA do cogumelo |
| 42 | Relé K1 | Saída | Via MOSFET |
| 47 | I²C SDA | — | Opcional |
| 48 | I²C SCL | — | Opcional |

O LED RGB da DevKitC‑1 fica no GPIO 38 (placa v1.1) ou 48 (v1.0) e pisca junto com o sinal desse pino; é só visual.

### 12.3 Placa, caixa e conectores

- **Placa de controle:** placa perfurada ilhada 10 × 15 cm com soquetes para o ESP32 e os 3 drivers, bornes KF301 e JST‑XH, sobre a placa de montagem impressa. Uma PCB própria (KiCad) é uma boa evolução.
- **Caixa:** ABS IP65 ~220 × 170 × 100 mm no andar de controle, com ESP32, drivers, ESCs, relé, fusíveis, conversores, receptor 433 MHz e capacitor; entradas por prensa-cabos.
- **Conectores entre andares** (nos suportes impressos): GX16‑4 para cada motor de passo, GX16‑8 para os sinais da cabeça e para o painel traseiro com o semáforo, GX16‑3 para o servo e o sensor do tubo; 2× MT60 para as fases das rodas.
- **Antenas:** cabo U.FL → SMA de painel. O ESP32 e o RXB6 ficam embaixo e as antenas no alto do andar do lançador: use uma extensão coaxial SMA (RG174, ~50 cm), solta antes de separar os andares.

## 13. Firmware e app

O firmware roda no ESP32‑S3 (Arduino via PlatformIO) e serve uma página web pelo próprio Wi‑Fi da máquina; a tela touch e o controle remoto permitem usar sem celular.

### 13.1 Bibliotecas

| Função | Biblioteca |
| --- | --- |
| Motores de passo (aceleração, posição) | FastAccelStepper |
| Configuração dos TMC2209 | TMCStepper |
| PWM dos ESCs e do servo | LEDC nativo do ESP32 (ou ESP32Servo) |
| Servidor web e tempo real | ESPAsyncWebServer + AsyncTCP (WebSocket) |
| Mensagens (app e tela) | ArduinoJson |
| Controle remoto 433 MHz | rc-switch |
| Semáforo | Adafruit NeoPixel (ou FastLED) |
| Calibração salva | Preferences (NVS) |
| Página do app | LittleFS |
| Atualização sem cabo | ElegantOTA |
| Tela (no ESP32‑S3 da própria tela) | LVGL + LovyanGFX |

### 13.2 Tarefas

1. **Controle de RPM (100 Hz, núcleo 1):** mede o período entre pulsos Hall (2 por volta), calcula o acelerador de cada ESC e sinaliza "pronto".
2. **Sequenciador de disparos:** máquina de estados que posiciona giro e tilt, libera a bola, espera "pronto", faz a contagem no semáforo e aciona o empurrador.
3. **Segurança (50 Hz):** botão de emergência, tensão das baterias, tempos-limite de sensores e sinal de vida do app.
4. **Comunicação e interface (núcleo 0):** Wi‑Fi, página web, WebSocket, tela, controle remoto e semáforo.

### 13.3 Controle de RPM

```math
acel = FF(RPM_{alvo}, V_{bat}) + K_p \cdot e + K_i \int e\,dt
```

- **Feedforward (FF):** tabela acelerador → RPM levantada automaticamente na calibração (varre de 10% a 80% e grava), corrigida pela tensão da bateria. Faz o grosso do trabalho; o PI só corrige o resto.
- **Antiwindup:** o integrador congela quando o acelerador satura.
- **Rampa:** no máximo ~1.500 rpm/s, para manter a corrente total abaixo de 25 A e poupar as correias (mais lenta com fonte AC).
- **Pronto:** erro < 1,5% nas duas rodas por 300 ms seguidos.
- **Conversão do pedido do usuário:** velocidade e spin viram RPMs pelas fórmulas da seção 3, com η e k gravados na calibração.

### 13.4 Modos de treino

- **Manual:** velocidade, spin, direção, altura e intervalo; botão grande de iniciar/parar.
- **Predefinidos:** aquecimento, drive, topspin, slice, voleio, lob, bola rápida.
- **Programa (exercício):** lista de até 20 bolas, cada uma com velocidade, spin, giro, tilt e intervalo; repetir em ordem ou sortear. O controle remoto percorre os programas salvos.
- **Aleatório:** sorteia direção e/ou altura dentro de faixas escolhidas (treino de deslocamento).
- **Estacionar:** rodas a 0, giro ao centro e cabeça a 0°, antes de desligar e transportar.

### 13.5 App no celular

- A máquina cria a rede **Lancador‑XXXX**; a página abre em 192.168.4.1. Opcionalmente entra no Wi‑Fi do clube e responde em lancador.local.
- Telas: Controle, Programas, Calibração e Status (baterias, RPMs medidas, bolas lançadas, alarmes).
- A simulação da quadra no app considera também o vento (velocidade e direção); veja a seção 3.5.
- **Sinal de vida:** se o treino começou pelo app, o celular manda um ping por segundo; sem ping por 3 s, a máquina pausa a alimentação e só retoma com novo comando.

### 13.6 Tela, controle remoto e semáforo

- **Tela touch (sem o app):** os mesmos ajustes do modo manual, escolha do exercício, baterias e alarmes. Roda firmware próprio (LVGL) e só manda pedidos em JSON pela UART; quem verifica as condições de disparo é o controlador. Sem resposta por 1 s, a tela bloqueia os comandos.
- **Controle remoto 433 MHz:** A = iniciar/retomar; B = pausar; C = próximo exercício; D = configurável (padrão: estacionar). Pareamento pela tela ou pelo app (aperte um botão em até 10 s); outros códigos são ignorados. Código fixo pode ser copiado: o controle é conveniência, não segurança.
- **Semáforo:** vermelho fixo = parado ou rodas acelerando; amarelo piscando = próxima bola em breve (contagem); verde = disparo; tudo vermelho piscando = emergência ou falha. Brilho ajustável (mais alto ao sol).

### 13.7 Condições para disparar

Todas precisam ser verdadeiras: botão de emergência solto e relé K1 fechado; bola no tubo confirmada; giro e tilt na posição; as duas rodas "prontas"; baterias acima de 15,5 V; contagem do semáforo concluída; app conectado (só se o treino começou pelo app).

## 14. Lista de materiais — itens comprados

São ~70 linhas de compra, quase todas encontráveis no Mercado Livre, AliExpress ou em lojas de perfil de alumínio; a coluna "Especificação" é o termo de busca.

### 14.1 Estrutura e mecânica

| Item | Especificação | Qtd |
| --- | --- | --- |
| Perfil de alumínio | 20×20 canal 6, cortado conforme a lista da seção 5.2 (~4,1 m) | 16 peças |
| Cantoneira | Cantoneira 20×20 para perfil canal 6 | 4 |
| Porca-T | Porca-T M4 e M5 para canal 6 | 20 |
| Fechos | Fecho de pressão inox pequeno (tipo caixa de ferramentas) | 8 |
| Rolamento do giro | Lazy susan redondo Ø150 (6"), de esferas | 1 |
| Cantoneiras do garfo | Cantoneira de alumínio 40×40×3 (2 × 60 mm) | 1 barra 0,2 m |
| Mancal das rodas | KFL001 flange 2 furos, eixo 12 mm | 4 |
| Mancal do tilt | KFL08 flange, eixo 8 mm | 2 |
| Colar Ø8 | Colar trava eixo 8 mm | 4 |
| Colar Ø12 | Colar trava eixo 12 mm | 4 |
| Eixo das rodas de lançamento | Eixo retificado Ø12 h6 (2 × 140 mm) ou usinado (seção 16) | 1 barra 300 mm |
| Semi-eixos do tilt | Eixo retificado Ø8 (50 + 65 mm) | 1 barra 150 mm |
| Correias das rodas | Correia HTD 3M 9 mm fechada: 600‑3M‑9 e 288‑3M‑9 | 1 de cada |
| Polias dos motores | Polia HTD 3M 20 dentes, furo 5 mm, para correia de 9 mm | 2 |
| Polias das rodas | Polia HTD 3M 20 dentes, furo 12 mm, para correia de 9 mm | 2 |
| Espaçadores da cabeça | Espaçador de alumínio M5 × 90 mm | 4 |
| Pinos | Parafuso de ombro M6 × 30 (giro) e Ø6 × 6 rosca M5 (manivela) | 2 |
| Rolamento 608 | Ponta do fuso do giro | 1 |
| Tubo de queda | Cano PVC esgoto DN75 | 0,3 m |
| Trilhos-guia | Vareta de alumínio Ø8 (2 × 215 mm) | 0,5 m |
| Rodas de transporte | Roda de patins inline Ø125 × 24 + rolamentos 608 | 2 + 4 |
| Pés | Pé de borracha M8 regulável | 2 |
| Alça | Alça telescópica de mala (reposição, 2 tubos) | 1 |
| Varetas do cesto | Vareta ou tubo de alumínio Ø8 (4 × ~285 mm + aro de ~1,95 m) | ~3,1 m |
| Tela do cesto | Tela de PVC/poliéster (tipo tela de cadeira), ~0,5 m², costurada em 4 painéis | 1 |
| Ímãs | Neodímio 6 × 3 mm | 10 |
| Microchaves | Fim de curso com alavanca (giro; tilt opcional) | 2 |
| Deslizante do agitador | Folha de PTFE ou UHMW 0,5 mm | 1 |
| Batentes | Batente de borracha M5 (repouso do tilt) | 4 |

### 14.2 Motores e eletrônica

| Item | Especificação | Qtd |
| --- | --- | --- |
| Motor das rodas | Brushless outrunner 4250 (Ø42 × 50 mm), 400–500 KV, eixo 5 mm invertível, ≥ 600 W | 2 |
| ESC | ESC brushless 60–80 A, 2–6S | 2 |
| Motor do giro | NEMA17 com fuso trapezoidal Tr8×8 integrado, 100 mm, com porca | 1 |
| Motor do tilt | NEMA17 com fuso trapezoidal Tr8×2 integrado (passo de 2 mm), 100 mm, com porca | 1 |
| Motor do agitador | NEMA17 curto (~34 mm) | 1 |
| Drivers | TMC2209 (módulo stepstick) | 3 |
| Microcontrolador | ESP32‑S3‑DevKitC‑1U‑N8R8 (conector U.FL) | 1 |
| Tela touch | Placa ESP32‑S3 com tela IPS 3,5" touch | 1 |
| Servo | Servo rápido 20–25 kg·cm, ≤ 0,07 s/60°, engrenagem metálica, tamanho padrão | 1 |
| Sensor de RPM | Módulo Hall A3144 | 2 |
| Sensor de bola | E18‑D80NK | 1 |
| Controle remoto | Receptor RXB6 433 MHz + controle chaveiro 4 botões 433 MHz | 1 + 1 |
| Antenas | Antena articulada SMA 433 MHz e 2,4 GHz | 1 de cada |
| Cabos de antena | Conector SMA fêmea de painel com cabo U.FL + extensão SMA RG174 ~50 cm | 2 + 2 |
| Semáforo | LEDs WS2812B (fita 60 LED/m, 12 LEDs) | 1 |
| Conversor 5 V | Buck LM2596 ou MP1584, 3 A | 1 |
| Conversor 6 V | Buck XL4015, 5 A | 1 |
| Conversor 12 V | Buck 1 A | 1 |
| Relé K1 | Relé automotivo 12 V 40 A + soquete | 1 |
| Acionador do relé | Módulo MOSFET nível lógico (AO3400 / IRLZ44N) | 1 |
| Buzzer | Buzzer ativo 5 V | 1 |
| Opcional | INA226 + shunt 50 A | 1 |

### 14.3 Potência, conectores e fiação

| Item | Especificação | Qtd |
| --- | --- | --- |
| Baterias (se ainda não tiver) | Makita BL1850B 18 V 5,0 Ah | 2 |
| Soquete de bateria | Adaptador para bateria Makita 18 V com fios 12 AWG | 2 |
| Diodo ideal | Módulo diodo ideal ≥ 30 A, 12–24 V | 2 (+1 com AC) |
| Chave liga/desliga | Chave eletrônica anti-faísca ≥ 60 A, 2–6S, com fio para chave externa | 1 |
| Botão liga/desliga | Botão 22 mm com retenção e anel de LED 12 V, 1NA | 1 |
| Botão de emergência | Cogumelo 22 mm, 1NA + 1NF (de painel) | 1 |
| Fusíveis | Porta-fusível lâmina inline + kit de fusíveis (2–30 A) | 8 |
| Conectores de potência | XT90, XT60, MT60 (3 vias), bullets 4 mm | kit |
| Conectores entre andares | Aviação GX16 (3, 4 e 8 pinos), pares | 7 |
| Fio | Silicone 12 AWG (1,5 m vermelho + 1,5 m preto), 14 AWG (2 m de cada), 18 e 22 AWG | — |
| Cabo de motor de passo | Cabo manga 4 × 22 AWG | 3 m |
| Caixa | Caixa ABS IP65 ~220 × 170 × 100 mm | 1 |
| Prensa-cabos | PG7 / PG9 / PG11 | 10 |
| Placa | Placa perfurada ilhada 10 × 15 cm, bornes KF301, JST‑XH, barras de pinos | kit |
| Passivos | Resistores 330/1 k/10 k/12 k/20 k/100 k, capacitores 100 nF e 1.000 µF/35 V, diodo 1N4007 | kit |
| Acabamento | Termorretrátil, malha trançada, abraçadeiras | kit |

### 14.4 Entrada AC (opcional, fase 2)

| Item | Especificação | Qtd |
| --- | --- | --- |
| Fonte | Mean Well LRS‑350‑24 | 1 |
| Tomada | IEC C14 com porta-fusível e chave | 1 |
| Cabo de força | Cabo IEC C13, 3 m | 1 |

## 15. Peças impressas em 3D

São 35 tipos de peça (41 arquivos STL, contando as 4 partes da rampa e as 3 versões espelhadas), ~2,5–3 kg de PETG e ~0,4 kg de TPU; nada em PLA, porque na quadra, ao sol, o PLA amolece a partir de ~55 °C.

**Padrão (salvo indicação):** PETG, bico 0,4 mm, camada 0,2 mm, 4 perímetros, 30% gyroid, insertos de latão M3/M4/M5 colocados a quente onde houver parafuso. Peças expostas ao sol direto podem ser em ASA. As peças saem na posição de montagem: gire no fatiador para a melhor orientação.

| Peça | Material | Qtd | Notas |
| --- | --- | --- | --- |
| Núcleo da roda Ø134 × 32 mm | PETG, ASA ou PA‑CF | 2 | 6 perímetros, 60% gyroid, 5 camadas sólidas; ranhuras para a banda |
| Banda de rodagem Ø150 × 40 mm, perfil côncavo | TPU 95A | 2 + 2 reserva | 4 perímetros, 50% gyroid, 20–30 mm/s, extrusora direta |
| Disco de sinal Ø40 × 8 mm (2 ímãs) | PETG | 2 | Preso no eixo, fora da placa |
| Suportes do sensor Hall, dos trilhos e do servo | PETG | 2 + 1 + 1 | Hall com ajuste de 2–4 mm até o disco |
| Berço da bola 90 × 77 × 22 mm | PETG | 1 | Rasgo do empurrador e furos dos trilhos |
| Funil da cabeça 90 × 145 × 19 mm | PETG | 1 | Boca 84 × 140 → Ø78 |
| Braço do empurrador | PETG + ponta em TPU | 1 | 100% infill no cubo do servo |
| Carenagens das rodas 89 × 170 × 111 mm | PETG ou ASA | 1 + 1 | De cima e de baixo |
| Tampas das correias | PETG | 1 + 1 | 27 × 201 × 253 mm (de cima) e 27 × 152 × 47 mm (de baixo); 2 espaçadores M3 cada |
| Suportes dos motores do giro (em L) e do tilt (no garfo −x) | PETG | 1 + 1 |  |
| Mancal da ponta do fuso do giro | PETG | 1 | Rolamento 608 |
| Blocos das porcas do giro e do tilt 28 × 24 × 28 mm | PETG | 1 + 1 | Rasgo para o pino |
| Rotor do agitador Ø220 × 56 mm | PETG | 1 | Disco com cúpula e 4 bolsões; cabe em mesa de 235 mm |
| Capuz do furo de saída 116 × 88 × 70 mm | PETG | 1 |  |
| Rampas do alimentador | PETG | 4 partes | As 2 da frente têm 155 × 256 mm: mesa de 256 mm ou um corte a mais |
| Flange do tubo de queda 103 × 102 × 15 mm | PETG | 1 |  |
| Dobradiças e cantos do cesto | PETG | 4 + 4 | Cantos: 2 espelhados; dobradiças presas no aro por M3 |
| Pinos de centragem e blocos dos pinos | PETG | 2 + 2 | Pino rosqueado (M5) no bloco; bloco preso no canal do poste |
| Pino-guia Ø10 do alimentador | PETG | 2 | M4 + porca-T na travessa do topo |
| Suporte dos conectores entre andares | PETG | 3 |  |
| Abraçadeira da alça 42 × 40 × 26 mm | PETG | 4 (2 espelhadas) |  |
| Berço do soquete de bateria 85 × 130 × 8 mm | PETG | 2 | Com guia de encaixe |
| Placa de montagem 200 × 154 × 3 mm | PETG | 1 | Dentro da caixa IP65 |
| Painel traseiro 249 × 26 × 100 mm | PETG ou ASA | 1 | Janela da tela e 2 furos de 22 mm |
| Semáforo: caixa com pala 132 × 46 × 44 mm e difusores Ø28 × 2 mm | ASA ou PETG preto; difusores em PETG natural | 1 + 3 |  |
| Suporte da antena | PETG | 2 (1 espelhado) | Leva o conector SMA de painel |

## 16. Peças metálicas terceirizadas

Todas as chapas saem de um único pedido de corte a laser (alumínio e aço, 10 arquivos DXF); os eixos podem ser barra retificada cortada em casa ou peça de torno.

### 16.1 Corte a laser

| Peça | Material | Espessura | Qtd | Dimensões aprox. | Notas |
| --- | --- | --- | --- | --- | --- |
| Piso do andar de controle | Alumínio 5052 | 3 mm | 1 | 312 × 422 mm | Berços das baterias, pés, caixa IP65 |
| Base do andar do lançador | Alumínio 5052 ou 6061 | 4 mm | 1 | 312 × 422 mm | Lazy susan, furo Ø40, pinos, giro, conectores |
| Base do alimentador | Alumínio 5052 | 3 mm | 1 | 312 × 422 mm | Furo de saída Ø76 em (0, −116), agitador, rampas |
| Aro do topo | Alumínio 5052 | 3 mm | 1 | 312 × 422 mm | Moldura de 30 mm |
| Placa lateral da cabeça | Alumínio 6061 | 6 mm | 2 | 347 × 310 mm | Mesma peça nos dois lados; oblongos na roda de baixo e nos motores |
| Garfo do tilt | Alumínio 6061 | 6 mm | 2 | 60 × 235 mm |  |
| Manivela do tilt | Alumínio 6061 | 6 mm | 1 | 42 × 87 mm | Furo em D para o semi-eixo |
| Plataforma giratória | Alumínio 5052 ou 6061 | 4 mm | 1 | 197 × 156 mm | Pino do giro a 102 mm |
| Suporte da roda de transporte | Alumínio 5052 | 4 mm | 2 | 70 × 100 mm |  |
| Discos de inércia | Aço 1020 | 3 mm | 4 | Ø120 mm | Furo em D + 6 × Ø4,4; zincar ou pintar |

O PDF de pranchas traz as cotas gerais de cada peça. Antes de enviar, confira com a peça na mão a furação de KFL001 (M6 a 48 mm), KFL08 (M4 a 37 mm), lazy susan e motor 4250.

### 16.2 Usinagem (opcional)

| Peça | Material | Qtd | Especificação |
| --- | --- | --- | --- |
| Eixo da roda de lançamento | Aço 1045 retificado | 2 | Ø12 h6 × 140 mm, chato de 1 mm em todo o comprimento |
| Semi-eixo do tilt | Aço retificado Ø8 | 2 | Lado +x: 50 mm; lado −x: 65 mm com chato (7 mm entre faces) na ponta |
| Eixo da roda de transporte | Aço | 2 | Ø8 × 60 mm; pode ser um parafuso de ombro Ø8 |

Se preferir não terceirizar: compre barra retificada Ø12 e Ø8, corte com serra de metal e faça os chatos com lima ou esmerilhadeira.

### 16.3 O que enviar ao fornecedor

- **DXF em escala 1:1, em milímetros**, uma peça por arquivo, só com contornos fechados.
- **Planilha do pedido:** peça, material, espessura e quantidade. Nenhuma chapa da v2 é dobrada.
- **Furos:** diâmetro mínimo = espessura da chapa. O laser não faz rosca: marque os furos a rosquear (M4, M5, M6) e rosqueie em casa com macho.
- **Tolerância:** ±0,2 mm é o normal do laser e basta, porque os mancais são parafusados (não há encaixe sob pressão).
- **Acabamento:** peça rebarbação. Anodizar ou pintar é opcional.
- **Fornecedor:** serviços brasileiros com orçamento por upload de DXF, ou metalúrgica local com laser de fibra. Compare 2–3 orçamentos; agrupar tudo num pedido reduz bastante o custo. Serviços do exterior somam frete e imposto de importação.

### 16.4 Carenagem (só STEP, material a definir)

A carenagem não vai no pedido de laser. Os 4 STEP (três painéis e a tampa das baterias) são a referência de forma e de recortes para o material escolhido:

- **Molde injetado (ABS ou PP):** melhor acabamento e resistência; o molde só compensa em lote.
- **Termoformagem** em chapa de ABS ou PETG: molde simples, bom para poucas unidades; recortes feitos depois.
- **Impressão em partes** (PETG ou ASA), unidas por parafuso ou cola: sem molde, muitas horas de impressão.
- **ACM ou chapa composta:** painéis planos; os cantos R30 viram cantos vivos ou peças de canto impressas.

Ajuste a espessura de parede ao material e confira de novo a folga até a cabeça.

## 17. Fixadores e consumíveis

Compre um kit de parafusos allen inox M3–M6 e os itens abaixo; tudo que gira ou vibra leva trava-rosca.

| Item | Qtd aprox. | Uso |
| --- | --- | --- |
| Parafusos M6 × 20 + porcas autotravantes | 8 | KFL001 nas placas laterais (48 mm entre furos) |
| Parafusos M4 × 16 + porcas autotravantes | 4 | KFL08 no garfo (37 mm entre furos) |
| Parafusos M4 × 45 + porcas autotravantes | 12 | Discos de aço + núcleo das rodas |
| Parafusos M5 × 12 (cilíndrica e escareada) | 40 | Postes nas chapas; espaçadores da cabeça |
| Parafusos M5 e M4 para porca-T | 20 | Blocos dos pinos, pinos-guia, suportes das antenas |
| Parafusos M4 × 10–16 + porcas | 40 | Lazy susan, cantoneiras do garfo, peças impressas nas chapas |
| Parafusos M3 × 8 / × 10 | 40 | NEMA17 (31 mm), X‑mount dos 4250 (r 19 mm), sensores |
| Espaçadores M3 (~20 mm) | 4 | Tampas das correias |
| Parafusos M3 × 25 + porcas autotravantes | 4 | Pinos das dobradiças do cesto |
| Parafusos M3 ou rebites 3 mm | 32 | Fechos de pressão |
| Porcas M8 + arruelas | 4 | Pés de borracha no piso |
| Insertos de latão M3, M4 e M5 (colocação a quente) | 30 de cada | Peças impressas |
| Arruelas lisas e de pressão M3–M8 | kit |  |
| Trava-rosca média (azul) | 1 | Todo parafuso em peça que gira ou vibra |
| Cola PU ou adesivo instantâneo flexível | 1 | Banda de TPU no núcleo |
| Graxa branca de lítio | 1 | Fusos do giro e do tilt, lazy susan |
| Fita dupla face VHB | 1 rolo | Sensores e chicotes |
| Estanho 60/40 ou sem chumbo + fluxo | 1 | Solda da eletrônica |
| Macho de rosca M3, M4, M5 e M6 + desandador | 1 jogo | Furos das chapas e pontas dos perfis |

## 18. Sequência de montagem

Monte e teste a eletrônica na bancada antes de instalar, e a cabeça antes de colocá-la no garfo; depois monte um andar de cada vez, de baixo para cima.

1. **Preparação**
   - Imprima as peças, receba as chapas, rebarbe todas as bordas.
   - Rosqueie os furos marcados nas chapas e o furo central (M5) nas pontas de todos os postes; escareie os furos das bases do lançador e do alimentador.
2. **Eletrônica na bancada**
   - Solde a placa de controle e monte a caixa IP65 com conversores, ESCs, relé, fusíveis, receptor 433 MHz e conectores.
   - **Ajuste a saída dos conversores (5 V, 6 V, 12 V) antes de ligar qualquer carga.**
   - Teste cada subsistema com uma bateria (seção 19, passos 1–4), incluindo a tela e o pareamento do controle remoto.
3. **Andar de controle:** piso, postes de 112 mm, blocos e pinos de centragem, pés, suportes, eixos e rodas de transporte, berços e soquetes das baterias, diodos ideais, chave anti-faísca, caixa IP65 e suportes de conectores.
4. **Rodas de lançamento**
   - Núcleo + discos de aço + parafusos M4 (trava-rosca) + banda de TPU; polia no eixo.
   - Balanceamento estático (seção 6.2).
5. **Cabeça**
   - Placas laterais com espaçadores e KFL001; eixos, rodas e colares.
   - Motores por dentro das placas, polias por fora, correias esticadas pelos oblongos.
   - Ajuste o vão em 56 mm (um bloco de 56 mm serve de calibre) e aperte os mancais de baixo.
   - Sensores Hall, berço, funil, trilhos, servo e braço, carenagens das rodas, tampas das correias.
   - Gire cada roda à mão: livre, sem bater em nada e sem a correia pular dente.
6. **Andar do lançador**
   - Base, lazy susan, plataforma e garfo; atuador do giro (suporte, mancal 608, bloco-porca, pino) e microchave.
   - KFL08, cabeça com semi-eixos e colares, manivela, atuador do tilt.
   - Postes de 536 mm e quadro do topo; painel traseiro, semáforo, suportes das antenas, alça.
   - À mão: giro ±12,5° e tilt 0–30° sem prender e sem tocar em nada.
7. **Andar do alimentador:** base, motor do agitador por baixo, PTFE, rotor, capuz, rampas, postes de 79 mm, aro do topo, flange e tubo com sensor.
8. **Cesto:** dobradiças, varetas, cantos e aro de cima, tela. Confira que dobra e abre sem forçar a tela.
9. **Empilhar:** controle → lançador (pinos de centragem) → alimentador (pinos-guia); ligue os conectores entre andares.
10. **Fiação final**
    - Chicote da cabeça pelo furo central com laço de 15–20 cm.
    - Potência: soquetes → fusíveis → diodos ideais → chave anti-faísca → barramento → relé → ESCs.
    - Sem bateria: confira polaridade e continuidade de cada ligação.
11. **Proteções:** carenagens das rodas e tampas das correias; carenagem externa e fechos, se houver.
12. **Comissionamento:** seção 19 completa.

## 19. Testes e comissionamento

São 13 testes em ordem, cada um com critério de aprovação; só avance quando o anterior passar.

| # | Teste | Como | Passa se |
| --- | --- | --- | --- |
| 1 | Inspeção sem energia | Multímetro entre + e − do barramento; fusíveis no lugar | Sem curto (a resistência sobe enquanto os capacitores carregam) |
| 2 | Primeira energia | Bateria com fusível temporário de 5 A no lugar do de 30 A | Botão liga e desliga a chave anti-faísca; 5,0 / 6,0 / 12 V corretos; nada esquenta |
| 3 | Leituras e interfaces | Firmware de teste mostra tensões e sensores na tela e no app | Baterias ±0,1 V do multímetro; cada sensor muda de estado; controle pareado; semáforo acende |
| 4 | Motores de passo | Comunicação UART, sentido, referência (homing) e limites | Giro e tilt voltam ao mesmo ponto em 10 referências seguidas; giro −12,5° a +12,5° e tilt 0° a +30° sem tocar em nada |
| 5 | Agitador | Liberar 20 bolas | 20 bolas, nenhuma dupla, nenhum travamento; detecta cesto vazio |
| 6 | Empurrador (rodas paradas) | 50 ciclos em 0°, 15° e 30° | A bola chega sempre até as rodas |
| 7 | ESCs | Calibrar a faixa do acelerador de cada ESC; conferir sentido | Nas duas rodas, a superfície que toca a bola anda para a frente (se não, troque 2 fases) |
| 8 | RPM em degraus | 1.000 → 2.000 → 3.000 rpm, 5 min a 3.000 | Hall = tacômetro óptico ±1%; sem vibração anormal nem salto de dente; motores e mancais < 50 °C |
| 9 | Rotação máxima | 5.500 rpm por 2 min, ninguém na lateral das rodas | Banda, parafusos, correias e carenagens intactos depois |
| 10 | Tabela de feedforward | Rotina automática de calibração | RPM alvo atingida em < 3 s, erro final < 1% |
| 11 | Primeiros disparos | 40 km/h, spin 0, tilt 0, em quadra vazia | Saída limpa, sem a bola raspar na carenagem da roda nem na janela |
| 12 | Calibração de η e k | Velocidade: app de radar ou vídeo em câmera lenta com distância marcada. Spin: bola riscada filmada em câmera lenta | Velocidade e spin medidos ±5% do pedido |
| 13 | Repetibilidade e segurança | 20 bolas iguais; botão de emergência com rodas girando; derrubar o Wi‑Fi num treino do app; pausar pelo controle | Dispersão < 1 m a 20 m; relé abre na hora; alimentação pausa em 3 s; controle pausa em < 0,5 s |

Depois disso, faça um treino completo com bateria cheia e anote a autonomia real para conferir a seção 3.4.

## 20. Segurança

Os dois riscos sérios desta máquina são as rodas a 5.500 rpm e a bola a 120 km/h; o resto é cuidado elétrico normal.

- **Plano das rodas:** se uma banda ou roda soltar, ela sai para os lados e para cima, no plano de giro. Nos testes de rotação alta, ninguém fica ao lado da cabeça.
- **Inspeção:** a cada ~10 h de uso, procure trincas no núcleo e desgaste na banda, confira o aperto dos parafusos M4 e a tensão e o desgaste das correias. O firmware nunca passa de 5.500 rpm.
- **Mãos fora da cabeça:** as rodas giram 10–30 s depois de desligar. Só mexa quando o app ou a tela mostrar 0 rpm. O modo manutenção bloqueia giro, tilt e empurrador.
- **Sem carenagem externa:** nunca rode sem as carenagens impressas das rodas e as tampas das correias, e mantenha as mãos fora do andar do lançador com a máquina ligada (giro e tilt prensam dedos).
- **Bola:** a 120 km/h machuca, principalmente olhos. Use óculos nos testes, mantenha crianças e curiosos atrás da máquina e nunca mire em pessoas fora do treino.
- **Controle remoto:** serve para pausar de longe, mas não é dispositivo de segurança; o botão de emergência fica na traseira.
- **Baterias:** fusível perto de cada fonte de energia; tire as baterias antes de mexer na fiação (a chave anti-faísca é eletrônica); não deixe a máquina com baterias ao sol sem uso; carregue só no carregador Makita.
- **AC (fase 2):** só com fonte fechada, terra ligado e revisão de um eletricista. Nunca abra a caixa da fonte com o cabo na tomada.
- **Peso:** ~20 kg sem carenagem. Para pôr no carro, levante em duas pessoas ou separe os andares.
- **Oficina:** bordas de chapa cortada a laser são afiadas (rebarbe); solde em local ventilado.

## Fontes

- [Goodwill, Chin & Haake (2004), Aerodynamics of spinning and non-spinning tennis balls](https://shura.shu.ac.uk/634/): arrasto e sustentação de bolas de tênis girando, base do simulador da seção 3.5.
- [Mean Well LRS‑350, folha de dados](https://www.meanwell.com/Upload/PDF/LRS-350/LRS-350-SPEC.PDF): faixa de ajuste, seleção de entrada e pico de carga.
- [PartsBuilt, adaptador Makita com corte de subtensão](https://partsbuilt.com/makita-18v-battery-adapter): exemplo de proteção extra contra descarga profunda.

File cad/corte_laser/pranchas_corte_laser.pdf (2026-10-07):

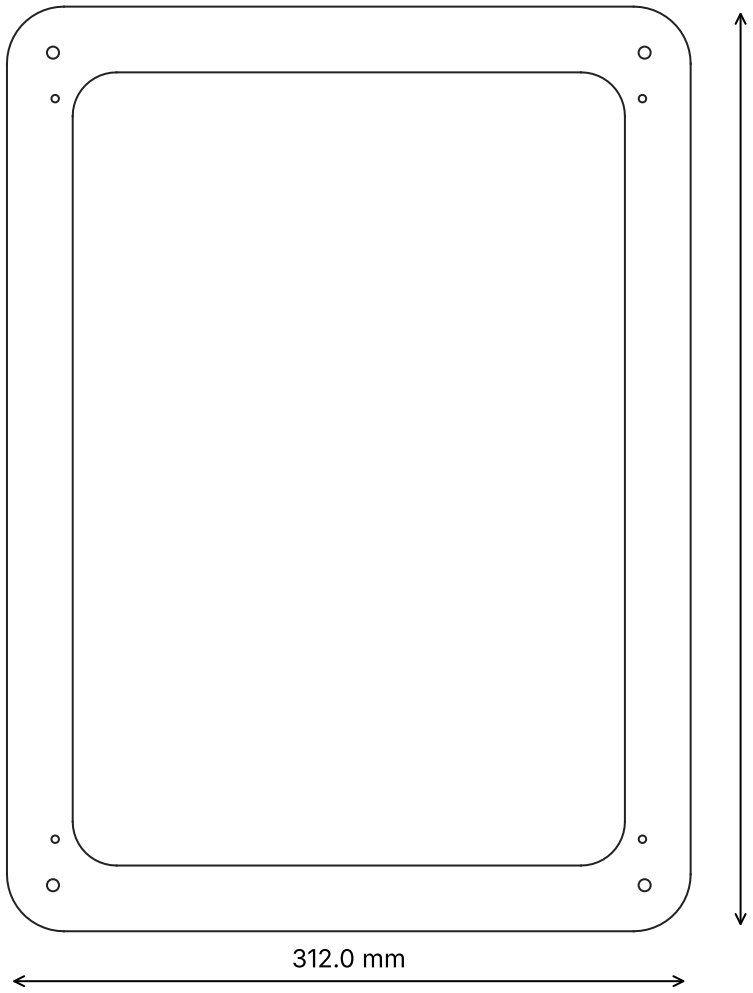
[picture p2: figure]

422.0 mm

## Aro do topo (assento do cesto, Al 3 mm) Alumínio 5052, 3 mm · quantidade: 1 · arquivo: aro_topo_3mm.dxf

Furos: 4× Ø3.4, 4× Ø5.5
Cotas em mm. Furos oblongos e recortes no DXF. Rosqueie em casa os furos marcados na seção 16 do documento.

## Base do alimentador (Al 3 mm)

## Alumínio 5052, 3 mm · quantidade: 1 · arquivo: chapa_alimentador_3mm.dxf

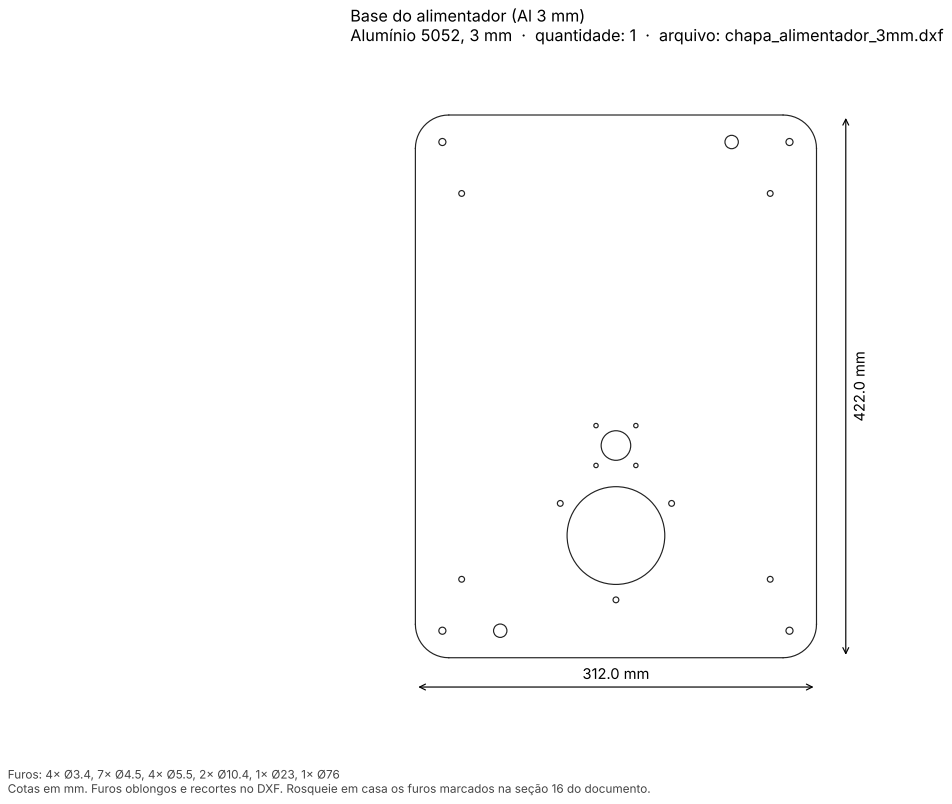
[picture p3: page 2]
Furos: 4× Ø3.4, 7× Ø4.5, 4× Ø5.5, 2× Ø10.4, 1× Ø23, 1× Ø76

## Base do andar do lançador (Al 4 mm)

## Alumínio 5052/6061, 4 mm · quantidade: 1 · arquivo: chapa_base_lancador_4mm.dxf

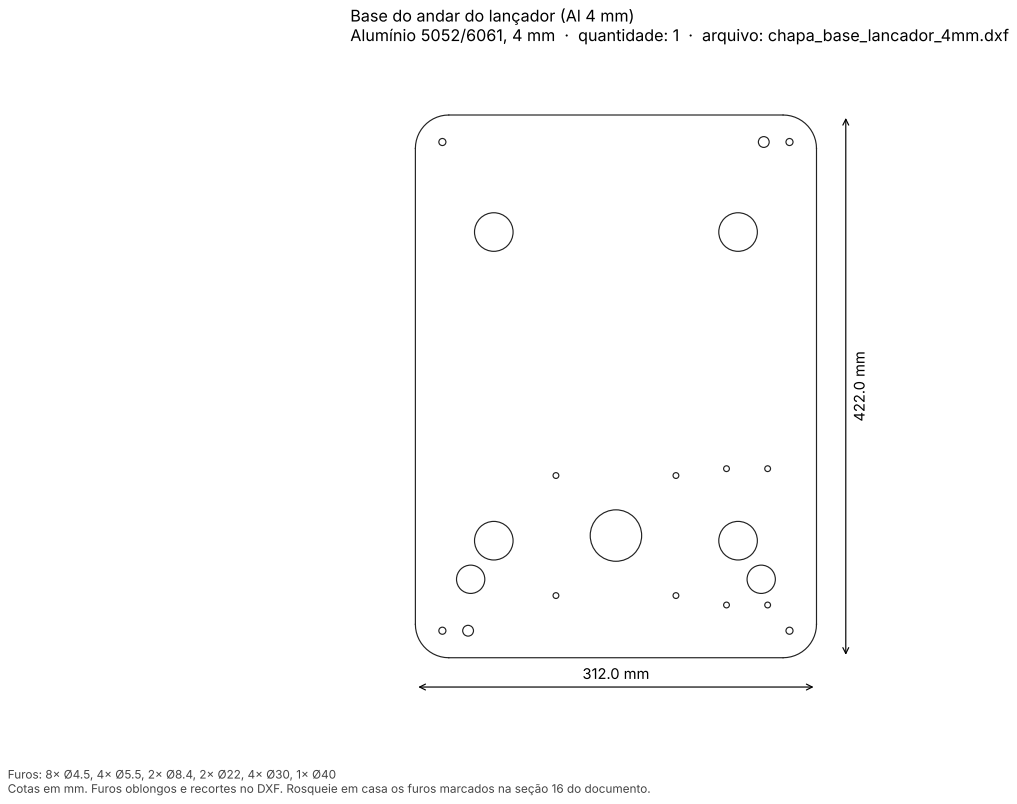
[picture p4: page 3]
Furos: 8× Ø4.5, 4× Ø5.5, 2× Ø8.4, 2× Ø22, 4× Ø30, 1× Ø40

## Piso do andar de controle (Al 3 mm)

## Alumínio 5052, 3 mm · quantidade: 1 · arquivo: chapa_piso_3mm.dxf

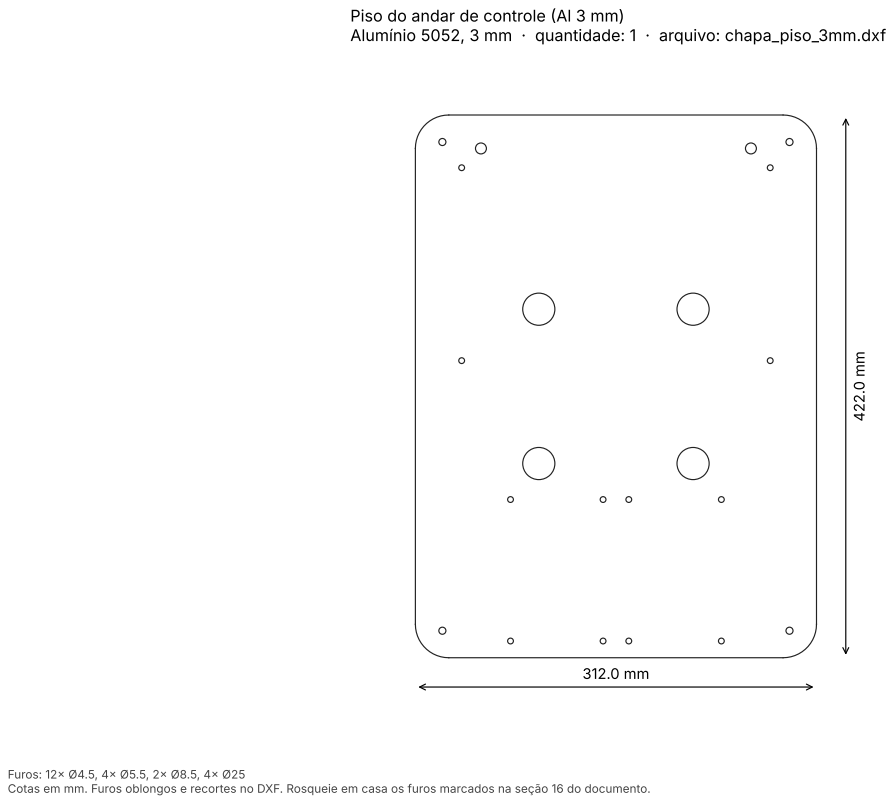
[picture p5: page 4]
Furos: 12× Ø4.5, 4× Ø5.5, 2× Ø8.5, 4× Ø25

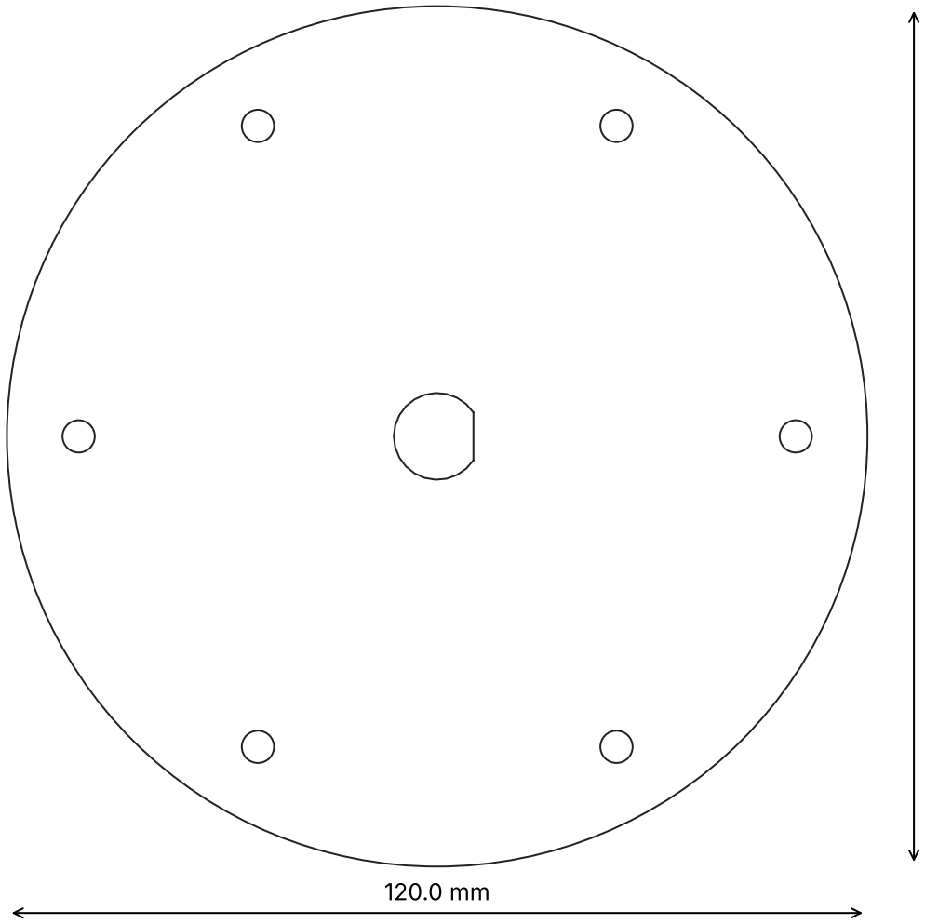
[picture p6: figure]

120.0 mm

## Disco de inércia Ø120 (aço 3 mm) Aço 1020, 3 mm · quantidade: 4 · arquivo: disco_inercia_3mm.dxf

Furos: 6× Ø4.5, 1× Ø120

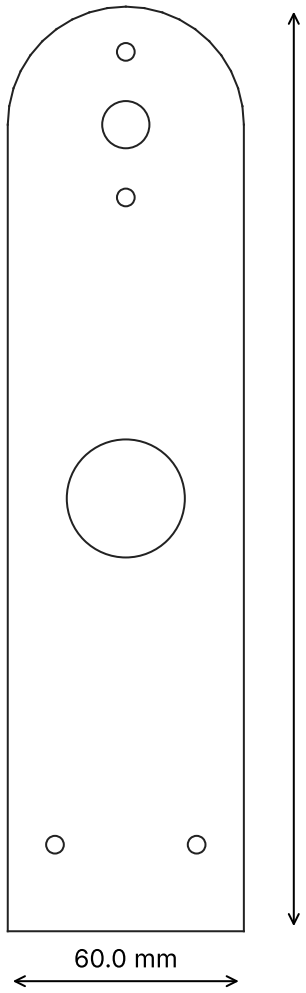
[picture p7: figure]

235.0 mm

## Garfo do tilt (Al 6 mm)

## Alumínio 6061, 6 mm · quantidade: 2 · arquivo: garfo_6mm.dxf

Furos: 4× Ø4.5, 1× Ø12, 1× Ø30

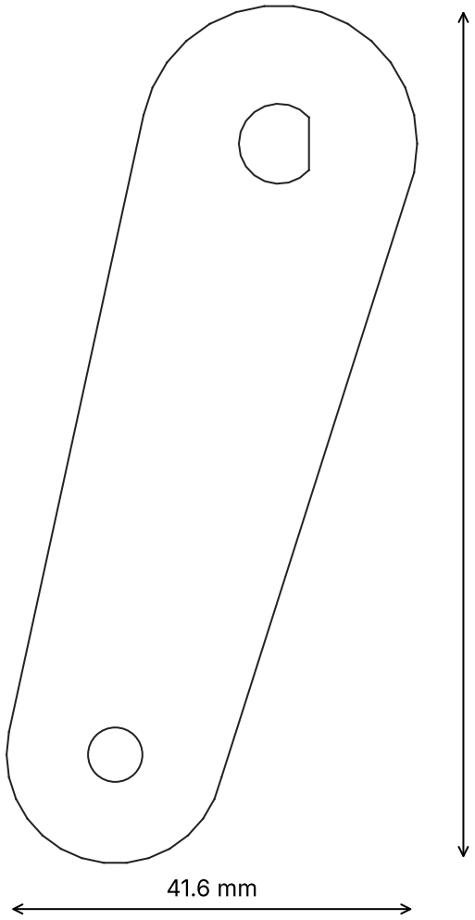
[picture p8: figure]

86.7 mm

## Manivela do tilt (Al 6 mm)

## Alumínio 6061, 6 mm · quantidade: 1 · arquivo: manivela_tilt_6mm.dxf

Furos: 1× Ø5.5

## Placa lateral da cabeça (Al 6 mm)

## Alumínio 6061, 6 mm · quantidade: 2 · arquivo: placa_lateral_6mm.dxf

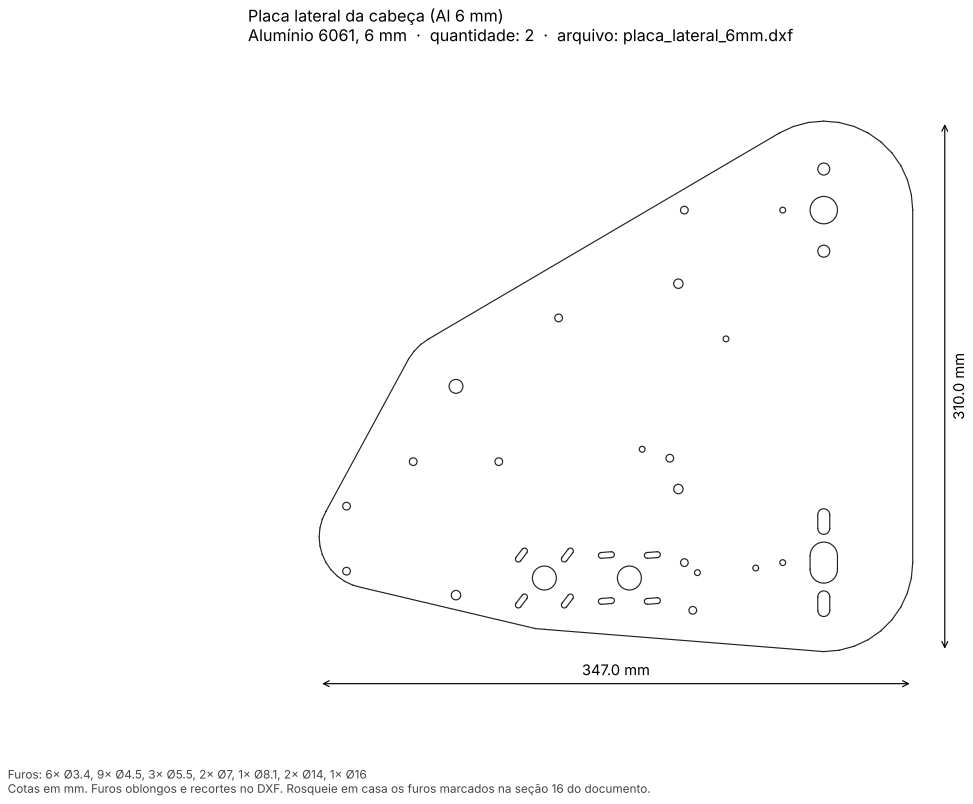
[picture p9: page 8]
Furos: 6× Ø3.4, 9× Ø4.5, 3× Ø5.5, 2× Ø7, 1× Ø8.1, 2× Ø14, 1× Ø16

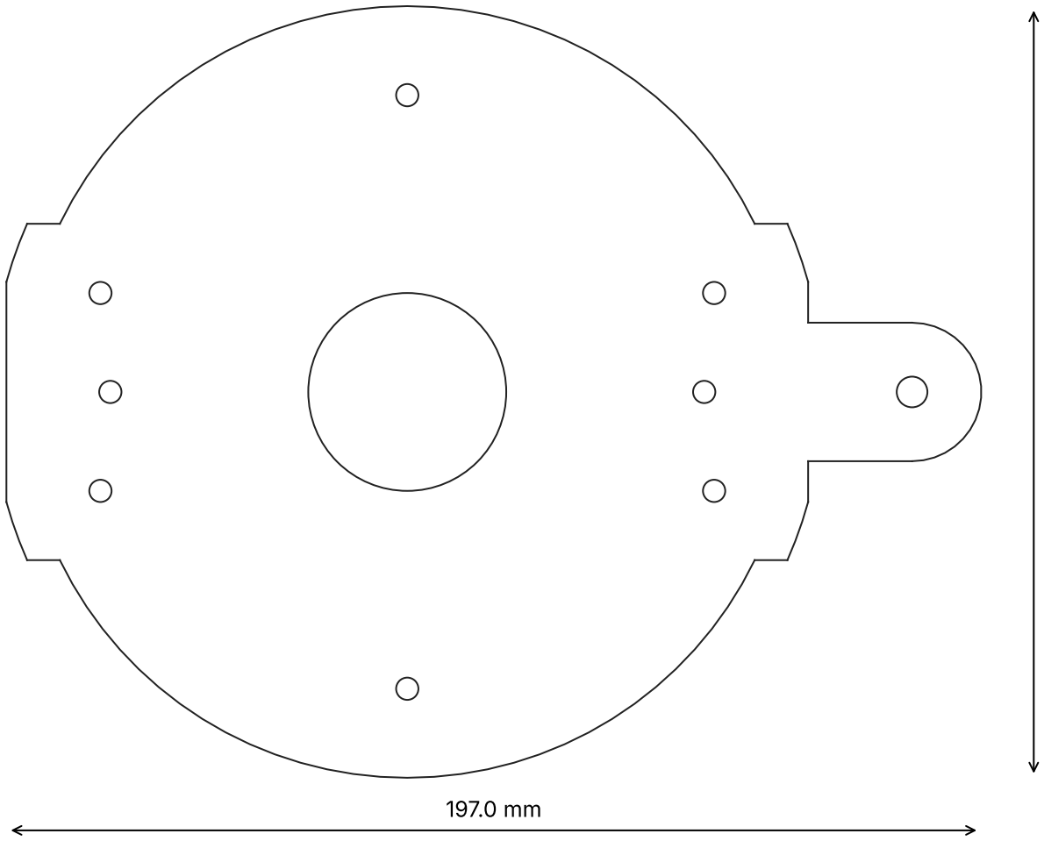
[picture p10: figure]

156.0 mm

## Plataforma giratória (Al 4 mm)

## Alumínio 5052/6061, 4 mm · quantidade: 1 · arquivo: plataforma_4mm.dxf

Furos: 8× Ø4.5, 1× Ø6.2, 1× Ø40

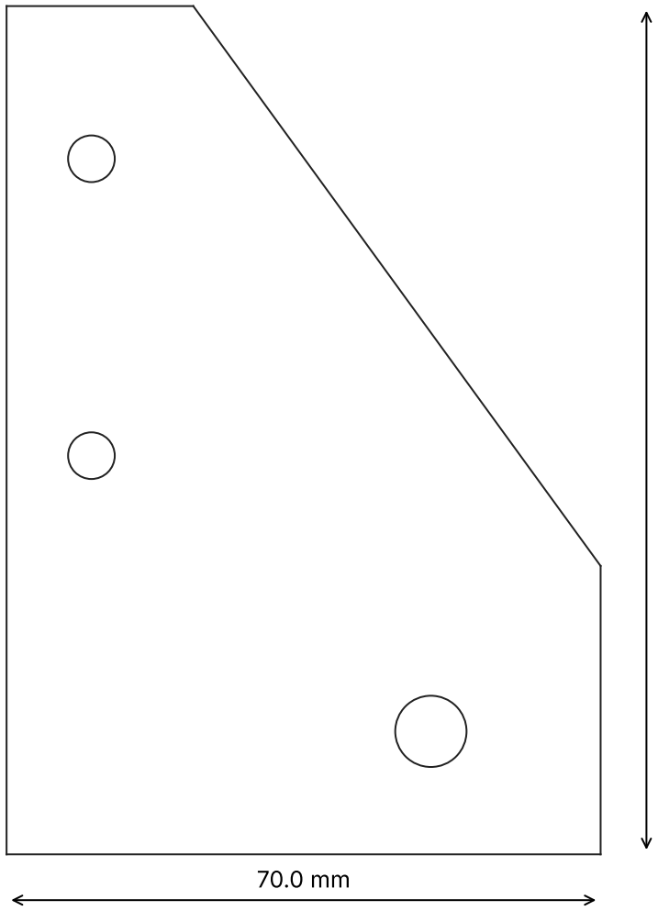
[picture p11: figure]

100.0 mm

## Suporte da roda de transporte (Al 4 mm)

## Alumínio 5052, 4 mm · quantidade: 2 · arquivo: suporte_roda_4mm.dxf

Furos: 2× Ø5.5, 1× Ø8.4

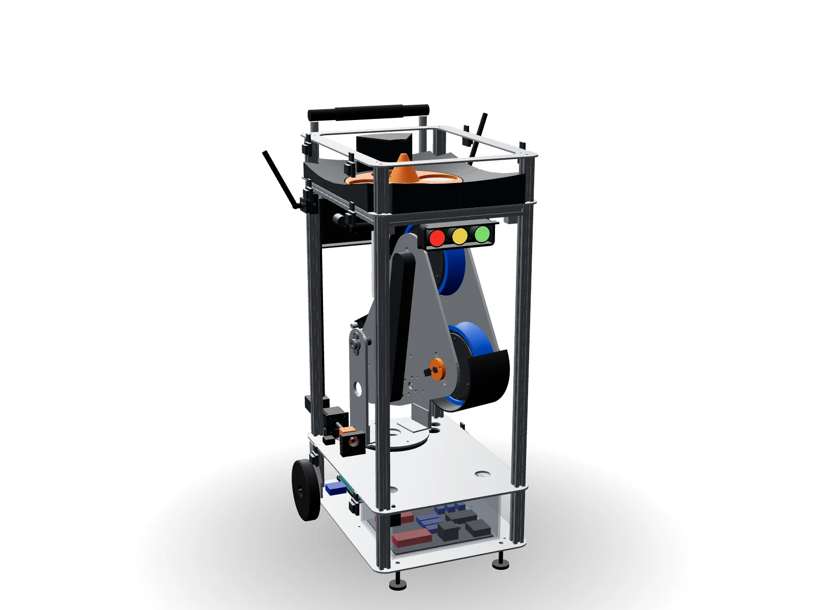
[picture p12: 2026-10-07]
assets/img/giro_sem.webp

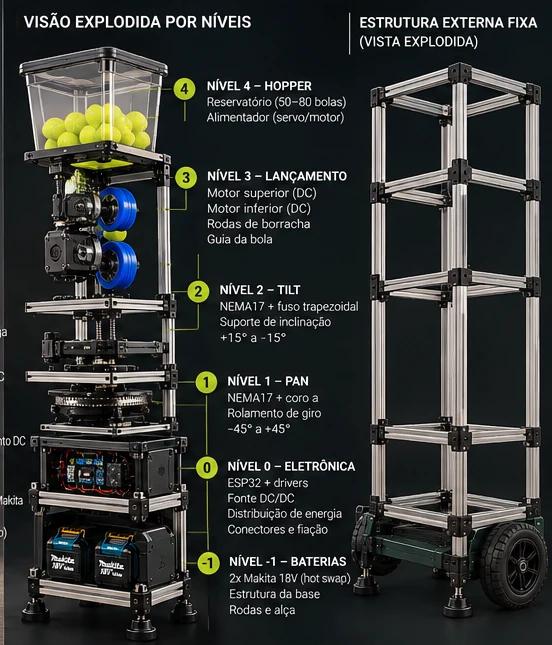
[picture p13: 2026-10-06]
assets/img/conceito_niveis.webp

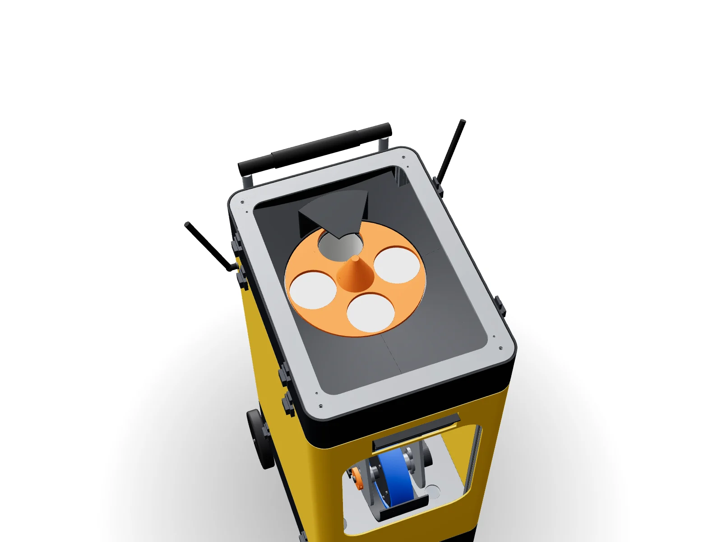
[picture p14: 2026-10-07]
assets/img/alimentador.webp

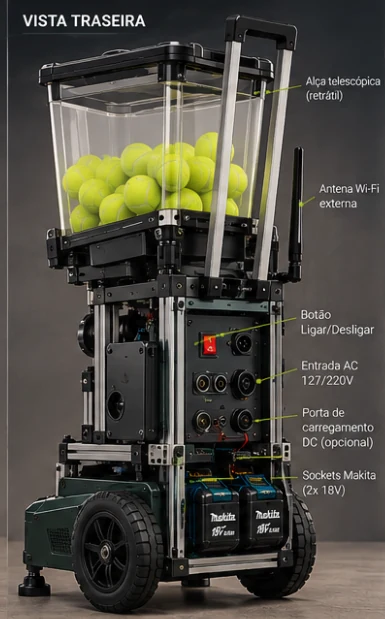
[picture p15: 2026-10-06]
assets/img/conceito_traseira.webp

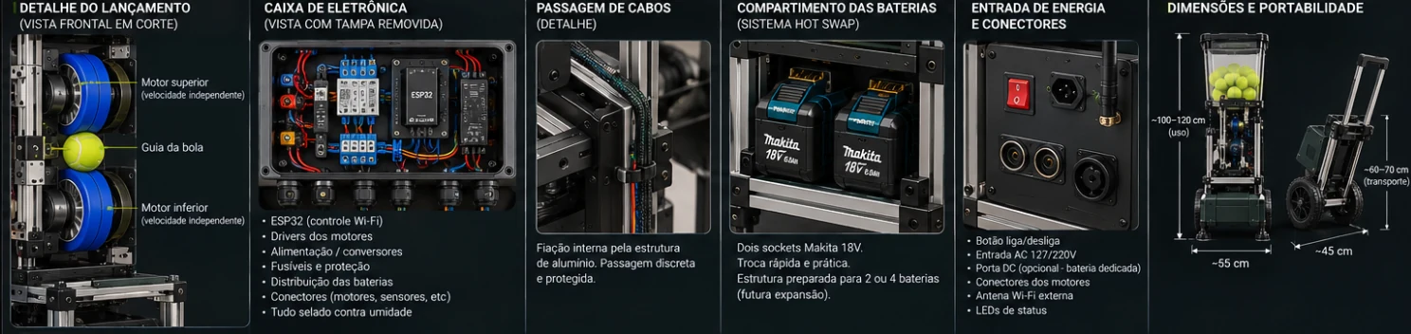
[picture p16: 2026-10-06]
assets/img/conceito_detalhes.webp

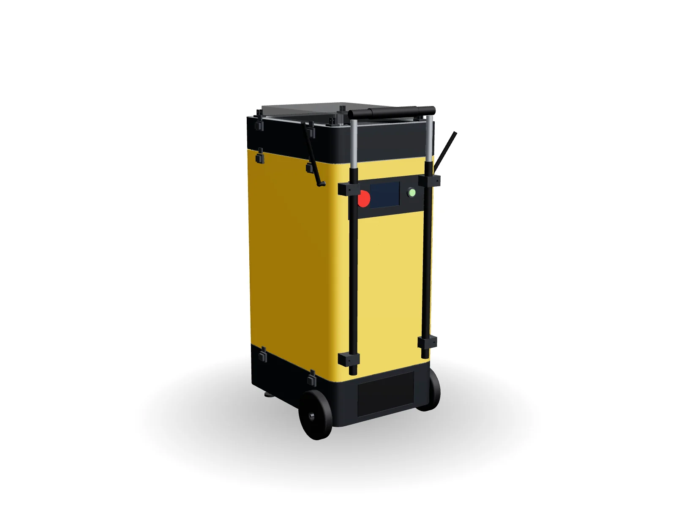
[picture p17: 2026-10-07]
assets/img/transporte.webp

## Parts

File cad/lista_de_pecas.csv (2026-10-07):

Categoria | Peça | Material | Qtd no modelo | Código | Arquivo(s)
Carenagem (material a definir) | Carenagem do alimentador | A definir | 1 | carenagem_alimentador | carenagem/carenagem_alimentador.step
Carenagem (material a definir) | Carenagem do andar de controle | A definir | 1 | carenagem_base | carenagem/carenagem_base.step
Carenagem (material a definir) | Carenagem do andar do lançador | A definir (molde injetado, termoformado, ABS/PETG ou ACM) | 1 | carenagem_lancador | carenagem/carenagem_lancador.step
Carenagem (material a definir) | Tampa das baterias | A definir | 1 | tampa_baterias | carenagem/tampa_baterias.step
Comprado pronto | Alça telescópica: tubo interno | Alumínio | 2 | alca_haste
Comprado pronto | Alça telescópica: tubo externo | Alumínio | 2 | alca_luva
Comprado pronto | Alça telescópica: pegador | Plástico | 1 | alca_pegador
Comprado pronto | Antena 433 MHz articulada SMA (controle remoto) |  | 1 | antena_433
Comprado pronto | Antena Wi-Fi 2,4 GHz articulada SMA (app) |  | 1 | antena_wifi
Comprado pronto | Aro de cima do cesto (varetas Ø8) | Alumínio Ø8 | 4 | aro_cesto
Comprado pronto | Bateria Makita 18 V 5,0 Ah |  | 2 | bateria_makita
Comprado pronto | Botão de emergência cogumelo 22 mm 1NA+1NF |  | 1 | botao_emergencia
Comprado pronto | Botão liga/desliga 22 mm com retenção e anel de LED |  | 1 | botao_liga
Comprado pronto | Caixa ABS IP65 ~220x170x100 | ABS | 1 | caixa_ip65
Comprado pronto | Cantoneira 20x20 para perfil canal 6 | Alumínio | 4 | cantoneira_2020
Comprado pronto | Cantoneira de alumínio 40x40x3 x 60 | Alumínio | 2 | cantoneira_garfo
Comprado pronto | Capacitor 1000 µF / 35 V |  | 1 | capacitor_1000uf
Comprado pronto | Chave eletrônica anti-faísca ≥60 A (liga/desliga) |  | 1 | chave_eletronica
Comprado pronto | Colar de trava Ø12 | Aço | 4 | colar_12
Comprado pronto | Colar de trava Ø8 | Aço | 4 | colar_8
Comprado pronto | Conector SMA de painel + cabo U.FL |  | 2 | conector_sma
Comprado pronto | Conversor buck |  | 3 | conversor_buck
Comprado pronto | Correia HTD 3M 9 mm fechada (600-3M-9 e 288-3M-9) | Borracha / fibra | 2 | correia_htd
Comprado pronto | Folha de PTFE/UHMW 0,5 mm sob o disco | PTFE | 1 | deslizante_ptfe
Comprado pronto | Módulo diodo ideal ≥30 A |  | 2 | diodo_ideal
Comprado pronto | Driver TMC2209 |  | 3 | driver_tmc2209
Comprado pronto | ESC brushless 60-80 A |  | 2 | esc_60a
Comprado pronto | ESP32-S3-DevKitC-1U (antena externa) |  | 1 | esp32_s3
Comprado pronto | Espaçador entre placas M5 x 90 | Alumínio | 4 | espacador_placas
Comprado pronto | Fecho de pressão inox pequeno (trava entre andares) | Inox | 8 | fecho_pressao
Comprado pronto | Rolamento lazy susan redondo Ø150 (6") | Aço | 1 | lazy_susan
Comprado pronto | LEDs WS2812B (3 grupos de 4) |  | 1 | leds_ws2812
Comprado pronto | Mancal KFL001 (Ø12) | Zamak / aço | 4 | mancal_kfl001
Comprado pronto | Mancal KFL08 (Ø8) | Zamak / aço | 2 | mancal_kfl08
Comprado pronto | Microchave fim de curso (referência do giro) |  | 1 | microchave
Comprado pronto | Motor de passo NEMA17 34 mm (agitador) |  | 1 | motor_agitador
Comprado pronto | NEMA17 com fuso Tr8x8 integrado 100 mm (giro) |  | 1 | motor_giro
Comprado pronto | Motor brushless outrunner 4250, 400-500 KV (eixo invertido) |  | 2 | motor_roda
Comprado pronto | NEMA17 com fuso Tr8x2 integrado 100 mm (tilt; passo de 2 mm, não volta sozinho) |  | 1 | motor_tilt
Comprado pronto | Parafuso M4 x 45 + porca autotravante |  | 12 | parafuso_m4_roda
Comprado pronto | Pé de borracha M8 regulável |  | 2 | pe_borracha
Comprado pronto | Pino do giro M6 x 30 (parafuso de ombro) |  | 1 | pino_giro
Comprado pronto | Pino da manivela: parafuso de ombro Ø6 x 6, M5 + porca |  | 1 | pino_manivela
Comprado pronto | Polia HTD 3M 20 dentes, furo 5, 15 mm | Alumínio | 2 | polia_motor
Comprado pronto | Polia HTD 3M 20 dentes, furo 12, 15 mm | Alumínio | 2 | polia_roda
Comprado pronto | Porta-fusíveis |  | 1 | porta_fusiveis
Comprado pronto | Receptor 433 MHz RXB6 (controle remoto) |  | 1 | receptor_433
Comprado pronto | Relé automotivo 40 A (K1) |  | 1 | rele_k1
Comprado pronto | Roda Ø125 x 24 com rolamentos 608 (patins inline) | PU | 2 | roda_transporte
Comprado pronto | Sensor Hall A3144 (módulo) |  | 2 | sensor_hall
Comprado pronto | Sensor infravermelho E18-D80NK (tubo) |  | 1 | sensor_tubo
Comprado pronto | Servo rápido 20-25 kg·cm, ≤ 0,07 s/60° (tamanho padrão, como o DS3225) |  | 1 | servo
Comprado pronto | Adaptador/soquete de bateria Makita 18 V |  | 2 | soquete_makita
Comprado pronto | Tela do cesto: 4 painéis de tela de PVC costurados | Tela de PVC/poliéster | 1 | tela_cesto
Comprado pronto | Tela touch 3,5" IPS com ESP32-S3 (controle sem app) |  | 1 | tela_touch
Comprado pronto | Trilho-guia da bola Ø8 x 215 (vareta de alumínio) | Alumínio | 2 | trilho_guia
Comprado pronto | Tubo de queda PVC DN75 x 230 | PVC esgoto DN75 | 1 | tubo_queda
Comprado pronto | Vareta do cesto (alumínio Ø8, ponta de baixo amassada e furada) | Alumínio Ø8 | 4 | vareta_cesto
Impressão 3D | Abraçadeira da alça | PETG | 4 | abracadeira_alca | impressao_3d/abracadeira_alca.stl impressao_3d/abracadeira_alca_espelhada.stl
Impressão 3D | Banda de rodagem TPU Ø150 x 40 | TPU 95A | 2 | banda_roda | impressao_3d/banda_roda.stl
Impressão 3D | Berço da bola | PETG | 1 | berco | impressao_3d/berco.stl
Impressão 3D | Berço do soquete de bateria | PETG | 2 | berco_bateria | impressao_3d/berco_bateria.stl
Impressão 3D | Bloco do pino (preso na face do poste) | PETG | 2 | bloco_pino | impressao_3d/bloco_pino.stl
Impressão 3D | Bloco da porca do giro (rasgo para o pino) | PETG | 1 | bloco_porca_giro | impressao_3d/bloco_porca_giro.stl
Impressão 3D | Bloco da porca do tilt (rasgo para o pino da manivela) | PETG | 1 | bloco_porca_tilt | impressao_3d/bloco_porca_tilt.stl
Impressão 3D | Braço do empurrador | PETG + ponta TPU | 1 | braco_empurrador | impressao_3d/braco_empurrador.stl
Impressão 3D | Canto de cima do cesto (2 + 2 espelhados) | PETG | 4 | canto_cesto | impressao_3d/canto_cesto.stl impressao_3d/canto_cesto_espelhada.stl
Impressão 3D | Capuz sobre o furo de saída | PETG | 1 | capuz_saida | impressao_3d/capuz_saida.stl
Impressão 3D | Carenagem da roda de baixo | PETG / ASA | 1 | carenagem_roda_inf | impressao_3d/carenagem_roda_inf.stl
Impressão 3D | Carenagem da roda de cima | PETG / ASA | 1 | carenagem_roda_sup | impressao_3d/carenagem_roda_sup.stl
Impressão 3D | Difusor do semáforo | PETG natural (translúcido) | 3 | difusor | impressao_3d/difusor.stl
Impressão 3D | Disco de sinal (2 ímãs) | PETG | 2 | disco_sinal | impressao_3d/disco_sinal.stl
Impressão 3D | Dobradiça do cesto (fixa no aro) | PETG | 4 | dobradica_cesto | impressao_3d/dobradica_cesto.stl
Impressão 3D | Flange do tubo de queda | PETG | 1 | flange_tubo | impressao_3d/flange_tubo.stl
Impressão 3D | Funil da cabeça (84x140 -> Ø78) | PETG | 1 | funil_cabeca | impressao_3d/funil_cabeca.stl
Impressão 3D | Mancal da ponta do fuso do giro (rolamento 608) | PETG | 1 | mancal_fuso_giro | impressao_3d/mancal_fuso_giro.stl
Impressão 3D | Núcleo da roda Ø134 x 32 | PETG / ASA / PA-CF | 2 | nucleo_roda | impressao_3d/nucleo_roda.stl
Impressão 3D | Painel traseiro (tela, liga/desliga, emergência) | PETG / ASA | 1 | painel_traseiro | impressao_3d/painel_traseiro.stl
Impressão 3D | Pino de centragem entre andares | PETG | 2 | pino_centragem | impressao_3d/pino_centragem.stl
Impressão 3D | Pino-guia Ø10 do alimentador (no canal da travessa) | PETG | 2 | pino_guia_topo | impressao_3d/pino_guia_topo.stl
Impressão 3D | Placa de montagem interna | PETG | 1 | placa_montagem | impressao_3d/placa_montagem.stl
Impressão 3D | Rampa do fundo do alimentador (1/4) | PETG | 4 | rampa_alimentador | impressao_3d/rampa_alimentador_1.stl impressao_3d/rampa_alimentador_2.stl impressao_3d/rampa_alimentador_3.stl impressao_3d/rampa_alimentador_4.stl
Impressão 3D | Rotor do agitador (disco Ø220 + cúpula) | PETG | 1 | rotor_agitador | impressao_3d/rotor_agitador.stl
Impressão 3D | Caixa do semáforo com pala | PETG / ASA preto | 1 | semaforo | impressao_3d/semaforo.stl
Impressão 3D | Suporte da antena | PETG | 2 | suporte_antena | impressao_3d/suporte_antena.stl impressao_3d/suporte_antena_espelhada.stl
Impressão 3D | Suporte dos conectores entre andares | PETG | 3 | suporte_conectores | impressao_3d/suporte_conectores.stl
Impressão 3D | Suporte do sensor Hall | PETG | 2 | suporte_hall | impressao_3d/suporte_hall.stl
Impressão 3D | Suporte do motor do giro | PETG | 1 | suporte_motor_giro | impressao_3d/suporte_motor_giro.stl
Impressão 3D | Suporte do motor do tilt (no garfo) | PETG | 1 | suporte_motor_tilt | impressao_3d/suporte_motor_tilt.stl
Impressão 3D | Suporte do servo | PETG | 1 | suporte_servo | impressao_3d/suporte_servo.stl
Impressão 3D | Suporte dos trilhos | PETG | 1 | suporte_trilho | impressao_3d/suporte_trilho.stl
Impressão 3D | Tampa da correia da roda de baixo | PETG | 1 | tampa_correia_inf | impressao_3d/tampa_correia_inf.stl
Impressão 3D | Tampa da correia da roda de cima | PETG | 1 | tampa_correia_sup | impressao_3d/tampa_correia_sup.stl
Corte a laser | Aro do topo (assento do cesto, Al 3 mm) | Alumínio 5052, 3 mm | 1 | aro_topo | corte_laser/aro_topo_3mm.dxf
Corte a laser | Base do alimentador (Al 3 mm) | Alumínio 5052, 3 mm | 1 | chapa_alimentador | corte_laser/chapa_alimentador_3mm.dxf
Corte a laser | Base do andar do lançador (Al 4 mm) | Alumínio 5052/6061, 4 mm | 1 | chapa_base_lancador | corte_laser/chapa_base_lancador_4mm.dxf
Corte a laser | Piso do andar de controle (Al 3 mm) | Alumínio 5052, 3 mm | 1 | chapa_piso | corte_laser/chapa_piso_3mm.dxf
Corte a laser | Disco de inércia Ø120 (aço 3 mm) | Aço 1020, 3 mm | 4 | disco_inercia | corte_laser/disco_inercia_3mm.dxf
Corte a laser | Garfo do tilt (Al 6 mm) | Alumínio 6061, 6 mm | 2 | garfo | corte_laser/garfo_6mm.dxf
Corte a laser | Manivela do tilt (Al 6 mm) | Alumínio 6061, 6 mm | 1 | manivela_tilt | corte_laser/manivela_tilt_6mm.dxf
Corte a laser | Placa lateral da cabeça (Al 6 mm) | Alumínio 6061, 6 mm | 2 | placa_lateral | corte_laser/placa_lateral_6mm.dxf
Corte a laser | Plataforma giratória (Al 4 mm) | Alumínio 5052/6061, 4 mm | 1 | plataforma | corte_laser/plataforma_4mm.dxf
Corte a laser | Suporte da roda de transporte (Al 4 mm) | Alumínio 5052, 4 mm | 2 | suporte_roda | corte_laser/suporte_roda_4mm.dxf
Perfil de alumínio (cortado sob medida) | Travessa frente/trás do topo (perfil 20x20, 250 mm) | Alumínio 20x20 canal 6 | 2 | perfil_topo_frente
Perfil de alumínio (cortado sob medida) | Travessa lateral do topo (perfil 20x20, 360 mm) | Alumínio 20x20 canal 6 | 2 | perfil_topo_lado
Perfil de alumínio (cortado sob medida) | Poste do alimentador (perfil 20x20, 79 mm) | Alumínio 20x20 canal 6 | 4 | poste_alimentador
Perfil de alumínio (cortado sob medida) | Poste do andar de controle (perfil 20x20, 112 mm) | Alumínio 20x20 canal 6 | 4 | poste_base
Perfil de alumínio (cortado sob medida) | Poste do andar do lançador (perfil 20x20, 536 mm) | Alumínio 20x20 canal 6 | 4 | poste_lancador
Usinagem / barra cortada | Eixo da roda Ø12 x 140 com chato | Aço 1045 retificado | 2 | eixo_roda | usinagem/eixo_roda.step
Usinagem / barra cortada | Eixo da roda de transporte Ø8 x 60 (parafuso de ombro) | Aço | 2 | eixo_roda_transporte | usinagem/eixo_roda_transporte.step
Usinagem / barra cortada | Semi-eixo do tilt Ø8 (lado +x 50 mm; lado -x 65 mm com chato na ponta) | Aço retificado | 2 | semi_eixo | usinagem/semi_eixo.step

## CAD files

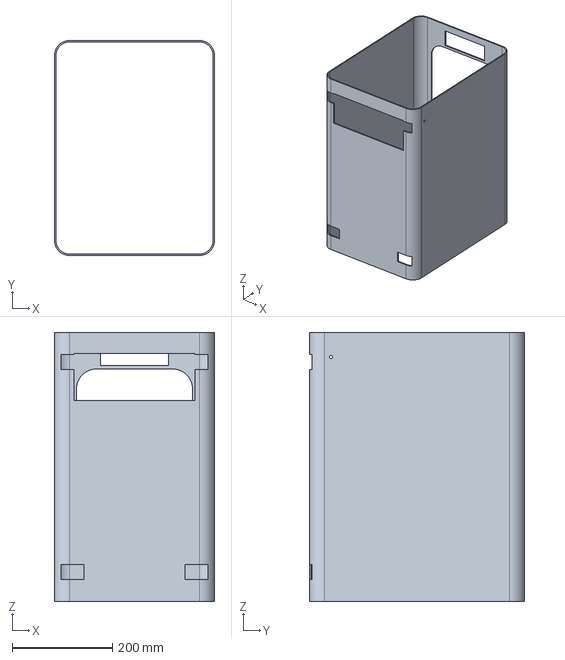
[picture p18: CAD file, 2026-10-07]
cad/carenagem/carenagem_lancador.step
320.0 x 430.0 x 538.0 mm

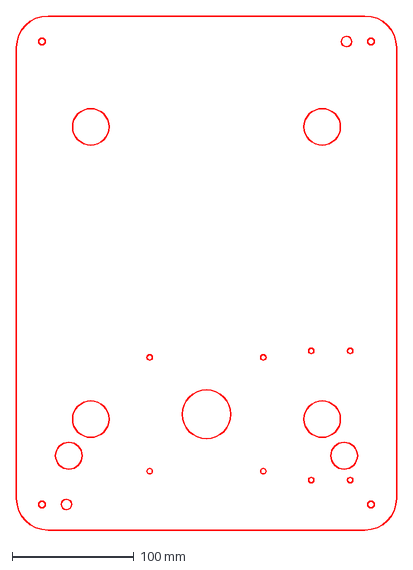
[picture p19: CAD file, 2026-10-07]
cad/corte_laser/chapa_base_lancador_4mm.dxf
312.0 x 422.0 mm

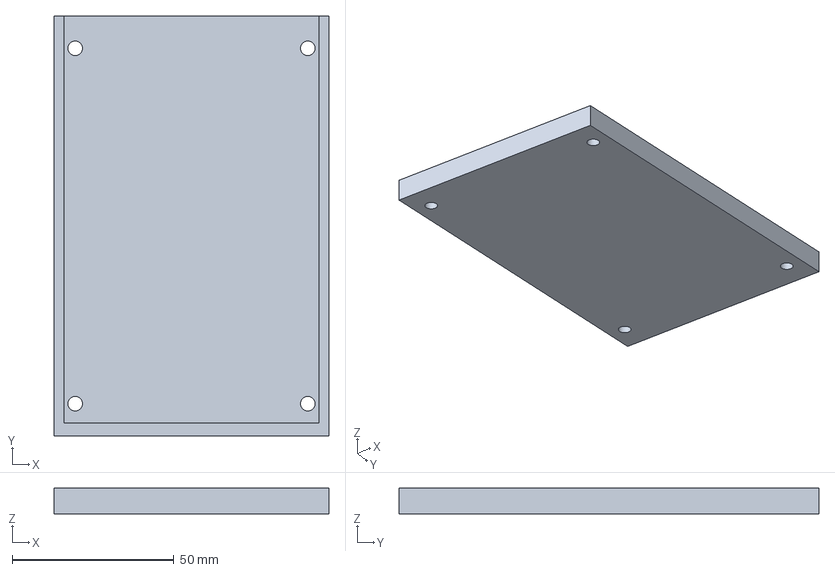
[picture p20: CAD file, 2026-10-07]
cad/impressao_3d/berco_bateria.step
85.0 x 130.0 x 8.00 mm

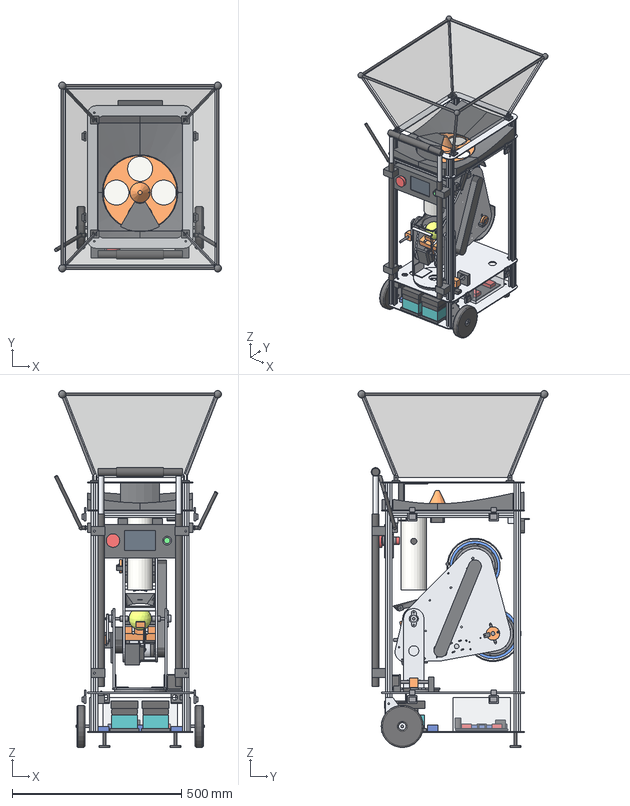
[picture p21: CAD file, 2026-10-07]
cad/montagem/lancador_montagem_sem_carenagem.step
494.1 x 561.7 x 1056.0 mm
chapa_piso__1
poste_base__1 x 4
pino_centragem__1
bloco_pino__1
pino_centragem__2
bloco_pino__2
berco_bateria__1
bateria_makita__1 x 2
bateria_makita_topo__1 x 2
soquete_makita__1
berco_bateria__2
soquete_makita__2
caixa_ip65__1
placa_montagem__1
esp32_s3__1
driver_tmc2209__1
driver_tmc2209__2
driver_tmc2209__3
esc_60a__1
esc_60a__2
rele_k1__1
porta_fusiveis__1
conversor_buck__1
conversor_buck__2
conversor_buck__3
receptor_433__1
capacitor_1000uf__1
diodo_ideal__1
diodo_ideal__2
chave_eletronica__1
suporte_roda__1
roda_transporte__1
eixo_roda_transporte__1
pe_borracha__1
suporte_roda__2
roda_transporte__2
eixo_roda_transporte__2
pe_borracha__2
fecho_pressao__1
fecho_pressao__2
fecho_pressao__3
fecho_pressao__4
suporte_conectores__1
suporte_conectores__2
chapa_base_lancador__1
lazy_susan__1
poste_lancador__1 x 4
perfil_topo_lado__1
perfil_topo_lado__2
perfil_topo_frente__1
perfil_topo_frente__2
cantoneira_2020__1
cantoneira_2020__2
cantoneira_2020__3
cantoneira_2020__4
motor_giro__1
fuso_giro__1
suporte_motor_giro__1
mancal_fuso_giro__1
bloco_porca_giro__1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

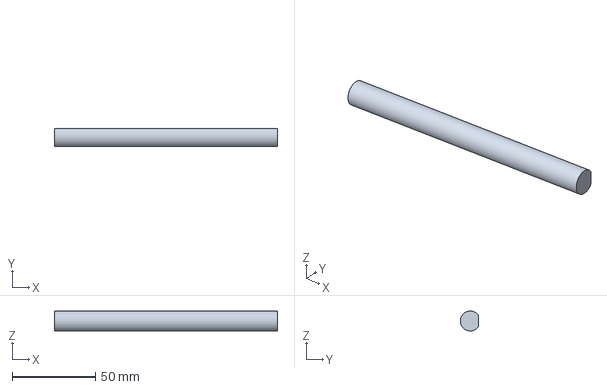
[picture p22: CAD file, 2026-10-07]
cad/usinagem/eixo_roda.step
134.0 x 11.0 x 12.0 mm

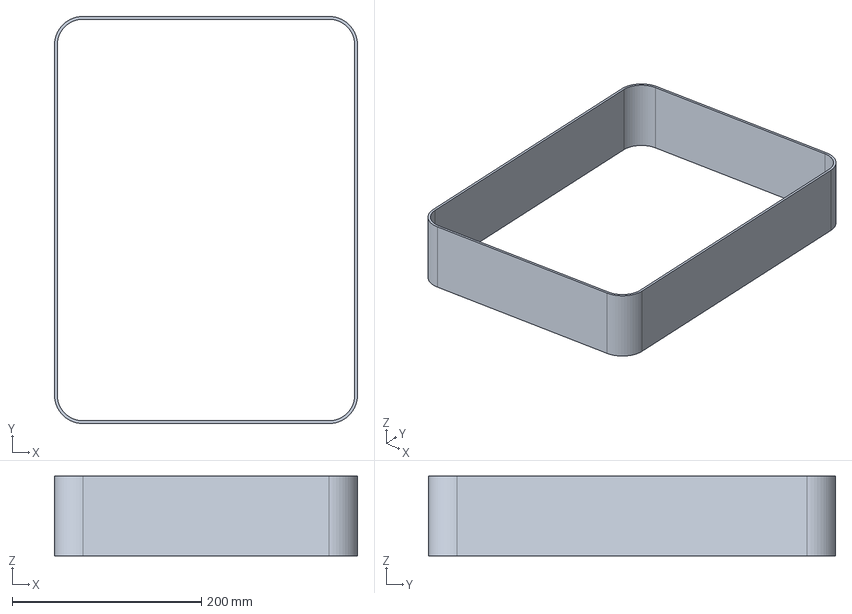
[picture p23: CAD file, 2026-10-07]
cad/carenagem/carenagem_alimentador.step
320.0 x 430.0 x 84.0 mm

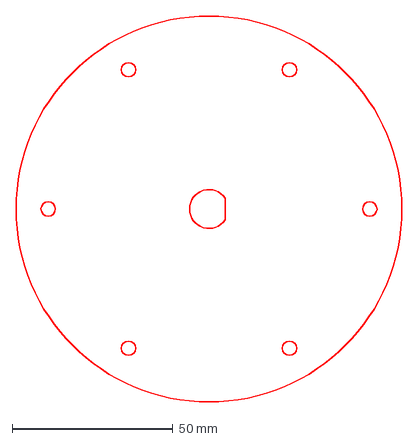
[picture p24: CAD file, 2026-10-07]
cad/corte_laser/disco_inercia_3mm.dxf
120.0 x 120.0 mm

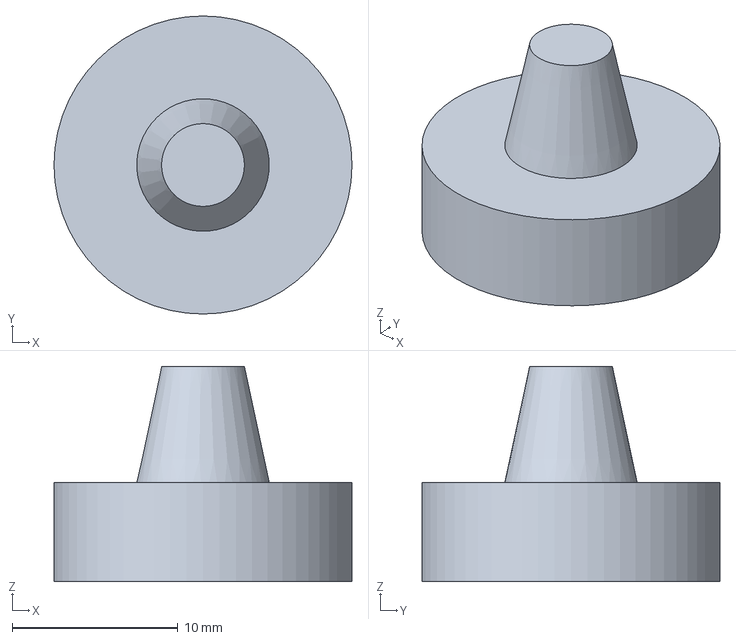
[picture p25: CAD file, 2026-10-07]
cad/impressao_3d/pino_centragem.step
18.0 x 18.0 x 13.0 mm

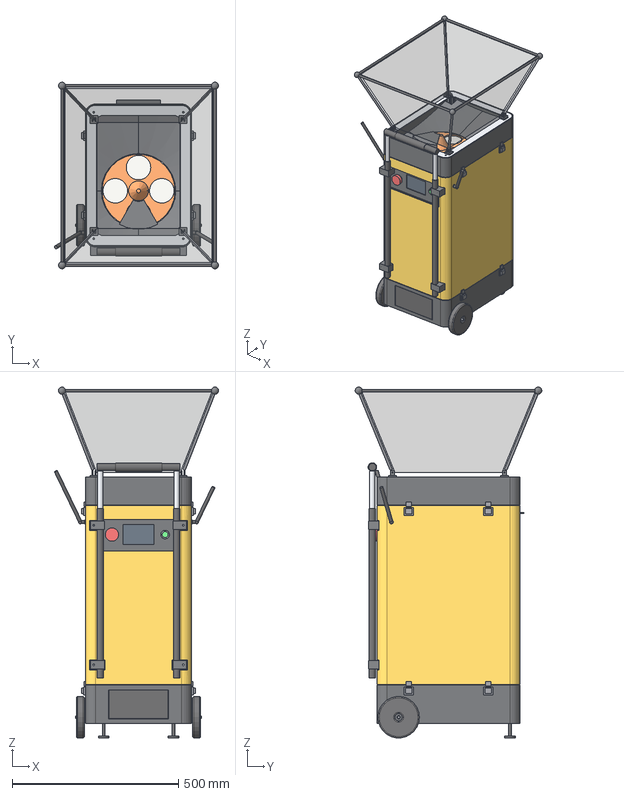
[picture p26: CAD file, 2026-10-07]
cad/montagem/lancador_montagem.step
494.1 x 561.7 x 1056.0 mm
chapa_piso__1
poste_base__1 x 4
pino_centragem__1
bloco_pino__1
pino_centragem__2
bloco_pino__2
berco_bateria__1
bateria_makita__1 x 2
bateria_makita_topo__1 x 2
soquete_makita__1
berco_bateria__2
soquete_makita__2
caixa_ip65__1
placa_montagem__1
esp32_s3__1
driver_tmc2209__1
driver_tmc2209__2
driver_tmc2209__3
esc_60a__1
esc_60a__2
rele_k1__1
porta_fusiveis__1
conversor_buck__1
conversor_buck__2
conversor_buck__3
receptor_433__1
capacitor_1000uf__1
diodo_ideal__1
diodo_ideal__2
chave_eletronica__1
suporte_roda__1
roda_transporte__1
eixo_roda_transporte__1
pe_borracha__1
suporte_roda__2
roda_transporte__2
eixo_roda_transporte__2
pe_borracha__2
fecho_pressao__1
fecho_pressao__2
fecho_pressao__3
fecho_pressao__4
suporte_conectores__1
suporte_conectores__2
carenagem_base__1
tampa_baterias__1
chapa_base_lancador__1
lazy_susan__1
poste_lancador__1 x 4
perfil_topo_lado__1
perfil_topo_lado__2
perfil_topo_frente__1
perfil_topo_frente__2
cantoneira_2020__1
cantoneira_2020__2
cantoneira_2020__3
cantoneira_2020__4
motor_giro__1
fuso_giro__1
suporte_motor_giro__1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

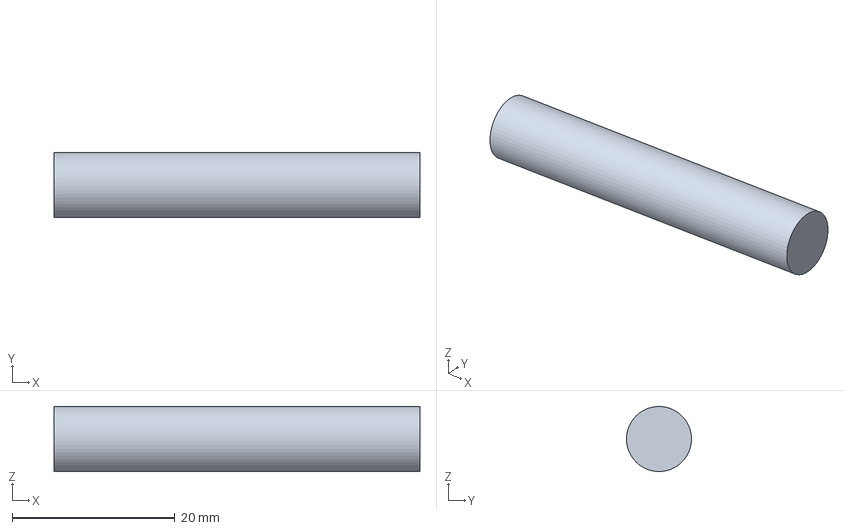
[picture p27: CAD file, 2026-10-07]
cad/usinagem/eixo_roda_transporte.step
45.0 x 7.99 x 8.00 mm

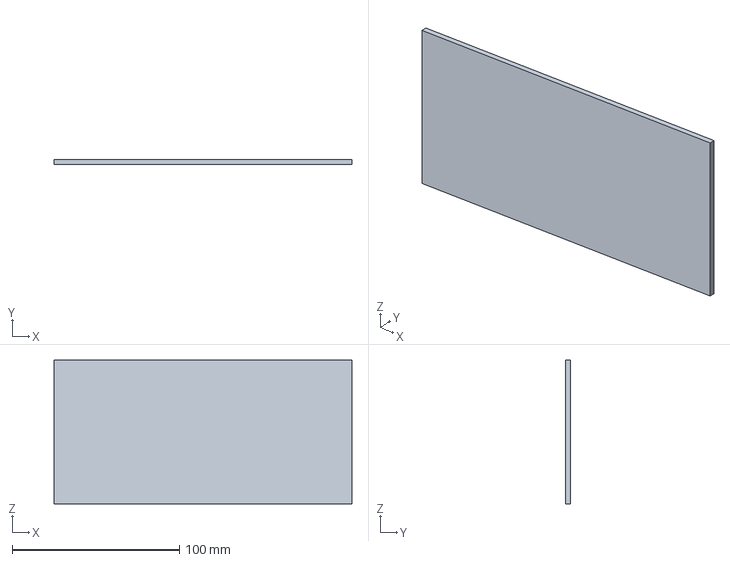
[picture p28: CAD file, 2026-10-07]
cad/carenagem/tampa_baterias.step
178.0 x 3.00 x 86.0 mm

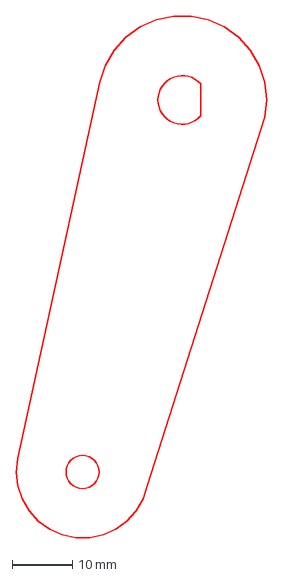
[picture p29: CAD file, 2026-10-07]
cad/corte_laser/manivela_tilt_6mm.dxf
41.6 x 86.7 mm

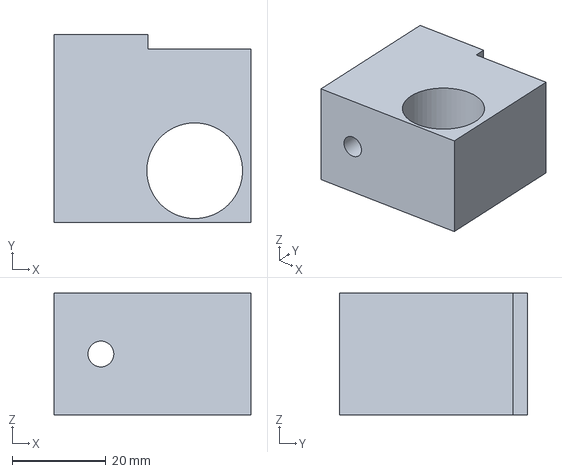
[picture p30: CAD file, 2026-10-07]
cad/impressao_3d/abracadeira_alca_espelhada.step
42.0 x 40.0 x 26.0 mm

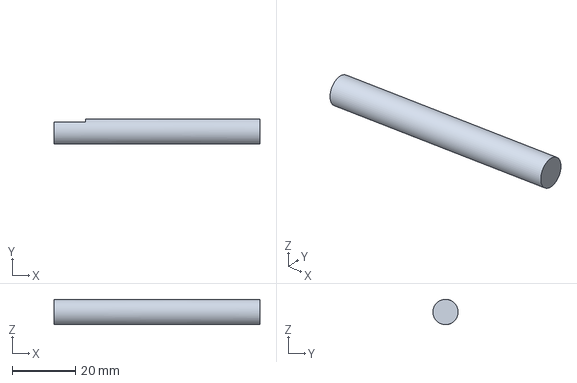
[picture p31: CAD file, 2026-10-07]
cad/usinagem/semi_eixo.step
65.0 x 8.00 x 8.00 mm

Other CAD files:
cad/carenagem/carenagem_base.step
cad/corte_laser/chapa_alimentador_3mm.dxf
cad/impressao_3d/flange_tubo.step
cad/corte_laser/plataforma_4mm.dxf
cad/corte_laser/aro_topo_3mm.dxf
cad/corte_laser/chapa_piso_3mm.dxf
cad/corte_laser/garfo_6mm.dxf
cad/corte_laser/placa_lateral_6mm.dxf
cad/corte_laser/suporte_roda_4mm.dxf
cad/impressao_3d/abracadeira_alca.step
cad/impressao_3d/abracadeira_alca.stl
cad/impressao_3d/abracadeira_alca_espelhada.stl
cad/impressao_3d/banda_roda.step
cad/impressao_3d/banda_roda.stl
cad/impressao_3d/berco.step
cad/impressao_3d/berco.stl
cad/impressao_3d/berco_bateria.stl
cad/impressao_3d/bloco_pino.step
cad/impressao_3d/bloco_pino.stl
cad/impressao_3d/bloco_porca_giro.step
cad/impressao_3d/bloco_porca_giro.stl
cad/impressao_3d/bloco_porca_tilt.step
cad/impressao_3d/bloco_porca_tilt.stl
cad/impressao_3d/braco_empurrador.step
cad/impressao_3d/braco_empurrador.stl
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

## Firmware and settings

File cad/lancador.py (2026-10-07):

"""
Lançador de bolas de tênis — versão 2 (compacta, por andares). Modelo paramétrico em CadQuery.

Unidades: mm. Eixos do mundo:
  x = largura (0 no centro), y = profundidade (+ para a frente), z = altura (0 no chão).
Referencial da cabeça (tilt): x igual ao mundo, "u" = para a frente ao longo da linha da bola,
"v" = para cima, origem no pivô do tilt (que fica sobre o eixo do giro).

Andares (de baixo para cima), cada um com placa de base + 4 postes 20x20:
  andar_base         rodas de transporte, pés, 2 baterias Makita, caixa IP65 do controle
  andar_lancador     rolamento do giro, plataforma, garfo, cabeça, atuadores de giro e inclinação,
                     painel traseiro (tela, liga/desliga, emergência), semáforo, antenas, alça
  andar_alimentador  disco agitador, rampas, tubo de queda
  cesto_aberto / cesto_dobrado   cesto de tela com varetas
  carenagem          painéis externos (material a definir) — liga/desliga no construir()

Hierarquia do giro e da inclinação:
  andar_lancador
   └─ pan          (gira em torno do eixo vertical x=0, y=YA)
       ├─ atuador_tilt   (articula na plataforma; o visualizador aponta o fuso para a manivela)
       └─ tilt           (inclina em torno do eixo x, a ZP do chão)
           ├─ roda_sup / roda_inf
           └─ ...

Rodar:  python3 exportar.py   -> gera a pasta saida/
"""
import math

import cadquery as cq

V = cq.Vector

# ----------------------------------------------------------------------------
# PARÂMETROS (mude aqui e rode de novo)
# ----------------------------------------------------------------------------
W, D = 320.0, 430.0            # carenagem externa (sem rodas e alça)
T_CAR = 3.0                    # espessura de referência da carenagem
R_CANTO = 30.0                 # raio dos cantos verticais da carenagem
P = 20.0                       # perfil 20x20
PX, PY = W / 2 - 25, D / 2 - 25   # centro dos postes (135, 190)
YA = -116.0                    # eixo do giro (y)

Z_BASE = 45.0                  # fundo do andar de controle (folga do chão)
T_PISO = 3.0
Z1 = 160.0                     # topo do andar de controle = base do andar do lançador
T_BASE_LANC = 4.0
LAZY_H = 8.0                   # lazy susan redondo Ø150
T_PLAT = 4.0
Z_PLAT = Z1 + T_BASE_LANC + LAZY_H + T_PLAT    # 176 topo da plataforma giratória
ZP = Z_PLAT + 205.0            # 381 linha da bola / pivô do tilt
Z2 = 700.0                     # topo do andar do lançador = base do alimentador
T_ALIM = 3.0
Z3 = 785.0                     # topo do alimentador (assento do cesto)
T_ARO = 3.0

PAN_MAX = 12.5                 # giro ±
TILT_MIN, TILT_MAX = 0.0, 30.0

NIP = 215.0                    # pivô -> nip (para a frente)
WHEEL_D, WHEEL_W, GAP = 150.0, 40.0, 56.0
WC = (WHEEL_D + GAP) / 2       # 103: altura dos eixos das rodas
BALL_R = 33.5
PL_IN, PL_T = 45.0, 6.0        # placas laterais: face interna a ±45, 6 mm
PL_OUT = PL_IN + PL_T          # 51
YOKE_IN, YOKE_T = 74.0, 6.0    # garfo: 74..80

# correias HTD 3M 9 mm, polias de 20 dentes (diâmetro primitivo 19,1)
POLIA_DP = 20 * 3.0 / math.pi
CORREIA_A, CORREIA_B = 600.0, 288.0   # comprimentos padrão (roda de cima / de baixo)
V_MOTOR = -112.0                      # altura dos dois motores (abaixo da linha da bola)


def _pos_motor(v_roda, comp):
    c = (comp - math.pi * POLIA_DP) / 2
    return (NIP - math.sqrt(c * c - (v_roda - V_MOTOR) ** 2), V_MOTOR)


MOT_A = _pos_motor(WC, CORREIA_A)     # motor da roda de cima (placa +x)  ~ (51,7, -112)
MOT_B = _pos_motor(-WC, CORREIA_B)    # motor da roda de baixo (placa -x) ~ (101,4, -112)
MOT_D, MOT_L = 42.0, 50.0

X_ATU = -115.0                 # plano do fuso do tilt (lado -x, por fora da manivela, que fica em x -100..-94)
X_MAN = -100.0                 # face externa da manivela
R_MAN = 64.0                   # raio da manivela; a 15° ela aponta para baixo, então a ponta anda quase só em u
MANIVELA = (-R_MAN * math.sin(math.radians(15)), -R_MAN * math.cos(math.radians(15)))   # ponta (u, v) com a cabeça a 0°
Z_FUSO_TILT = ZP - 63.0        # fuso do tilt deitado ao longo de u, preso no garfo

PAN_BRACO = 102.0              # raio do pino do giro no braço da plataforma (lado +x); motor livre do poste
Y_MOTOR_GIRO = YA - 44.0       # face do motor do giro (corpo para trás, fuso para a frente)
Y_MANCAL_GIRO = YA + 52.0      # rolamento 608 na ponta do fuso de 100 mm
Z_FUSO_PAN = Z1 + T_BASE_LANC + 30.0   # eixo do fuso do giro (horizontal, ao longo de y)

AGIT_C = (0.0, YA + 70.0)      # centro do disco agitador (furo de saída sobre o eixo do giro)
AGIT_R, AGIT_POCKET_R, AGIT_POCKET_D = 110.0, 70.0, 74.0
TUBE_BOTTOM = ZP + 85.0        # fim do tubo de queda (acima do funil da cabeça até +30°)

CESTO_H = 260.0
CESTO_TOPO = (460.0, 540.0)

# ----------------------------------------------------------------------------
# CORES
# ----------------------------------------------------------------------------
def _c(r, g, b, a=1.0):
    return cq.Color(r, g, b, a)


COR = {
    "perfil": _c(0.70, 0.72, 0.75),
    "alu": _c(0.80, 0.82, 0.85),
    "aco": _c(0.36, 0.37, 0.40),
    "petg": _c(0.17, 0.18, 0.20),
    "petg_laranja": _c(0.95, 0.45, 0.10),
    "tpu": _c(0.10, 0.38, 0.86),
    "motor": _c(0.12, 0.12, 0.13),
    "motor_sino": _c(0.62, 0.64, 0.68),
    "latao": _c(0.82, 0.64, 0.25),
    "makita": _c(0.0, 0.58, 0.60),
    "preto": _c(0.07, 0.07, 0.08),
    "borracha": _c(0.11, 0.11, 0.12),
    "caixa": _c(0.62, 0.65, 0.70, 0.30),
    "bola": _c(0.82, 0.94, 0.20),
    "vermelho": _c(0.85, 0.10, 0.10),
    "amarelo": _c(0.98, 0.80, 0.10),
    "pcb_verde": _c(0.05, 0.40, 0.20),
    "pcb_azul": _c(0.10, 0.25, 0.65),
    "pvc": _c(0.92, 0.92, 0.90),
    "correia": _c(0.10, 0.10, 0.10),
    "carenagem": _c(0.96, 0.74, 0.08),
    "grafite": _c(0.13, 0.14, 0.16),
    "malha": _c(0.08, 0.09, 0.10, 0.42),
    "led_vermelho": _c(0.95, 0.15, 0.12),
    "led_amarelo": _c(1.0, 0.75, 0.05),
    "led_verde": _c(0.15, 0.85, 0.30),
    "tela_lcd": _c(0.05, 0.12, 0.20),
}

# ----------------------------------------------------------------------------
# REGISTRO DE PEÇAS
# ----------------------------------------------------------------------------
PECAS = {}
_contador = {}

CAT = {
    "perfil": "Perfil de alumínio (cortado sob medida)",
    "laser": "Corte a laser",
    "impresso": "Impressão 3D",
    "usinado": "Usinagem / barra cortada",
    "comprado": "Comprado pronto",
    "carenagem": "Carenagem (material a definir)",
    "visual": "Só visualização",
}


def reg(base, label, cat, mat="", nota="", arquivo=None):
    if base not in PECAS:
        PECAS[base] = dict(label=label, cat=cat, mat=mat, nota=nota, qtd=0, shape=None, arquivo=arquivo)


def put(assy, shape, base, color, loc=None, **meta):
    if base not in PECAS:
        reg(base, meta.get("label", base), meta.get("cat", "comprado"), meta.get("mat", ""), meta.get("nota", ""))
    n = _contador.get(base, 0) + 1
    _contador[base] = n
    name = f"{base}__{n}"
    PECAS[base]["qtd"] += 1
    if meta.get("espelho"):                      # cópia espelhada: vira um segundo arquivo (…_espelhada)
        PECAS[base].setdefault("espelho_shape", shape)
    elif PECAS[base]["shape"] is None:
        PECAS[base]["shape"] = shape
    if meta.get("variante"):
        PECAS[base].setdefault("variantes", []).append(shape)
    assy.add(shape, name=name, color=color, loc=loc or cq.Location())
    return name


def ploc(origin, xdir, normal):
    return cq.Location(cq.Plane(origin=V(*origin), xDir=V(*xdir), normal=V(*normal)))


def rotz(deg):
    return cq.Location(V(0, 0, 0), V(0, 0, 1), deg)


def rotx(deg):
    return cq.Location(V(0, 0, 0), V(1, 0, 0), deg)


def tr(x, y, z):
    return cq.Location(V(x, y, z))


# ----------------------------------------------------------------------------
# PRIMITIVAS
# ----------------------------------------------------------------------------
def box(x0, x1, y0, y1, z0, z1):
    return cq.Workplane("XY").box(x1 - x0, y1 - y0, z1 - z0, centered=False).translate((x0, y0, z0))


def cyl_x(r, x0, x1, y=0.0, z=0.0):
    return cq.Workplane("YZ", origin=(x0, 0, 0)).center(y, z).circle(r).extrude(x1 - x0)


def cyl_y(r, y0, y1, x=0.0, z=0.0):
    return cq.Workplane("XZ", origin=(0, y1, 0)).center(x, z).circle(r).extrude(y1 - y0)


def cyl_z(r, z0, z1, x=0.0, y=0.0):
    return cq.Workplane("XY", origin=(0, 0, z0)).center(x, y).circle(r).extrude(z1 - z0)


def tube_z(ro, ri, z0, z1, x=0.0, y=0.0):
    return cq.Workplane("XY", origin=(0, 0, z0)).center(x, y).circle(ro).circle(ri).extrude(z1 - z0)


def tube_x(ro, ri, x0, x1, y=0.0, z=0.0):
    return cq.Workplane("YZ", origin=(x0, 0, 0)).center(y, z).circle(ro).circle(ri).extrude(x1 - x0)


def tube_y(ro, ri, y0, y1, x=0.0, z=0.0):
    return cq.Workplane("XZ", origin=(0, y1, 0)).center(x, z).circle(ro).circle(ri).extrude(y1 - y0)


def chapa(outline, t, furos=(), oblongos=(), recortes=()):
    """Chapa no plano XY local, espessura +Z. furos: (x, y, d); oblongos: (x, y, comprimento, largura, ang)."""
    s = outline.extrude(t)
    porD = {}
    for x, y, d in furos:
        porD.setdefault(d, []).append((x, y))
    for d, pts in porD.items():
        s = s.cut(cq.Workplane("XY").pushPoints(pts).circle(d / 2).extrude(t))
    for x, y, ln, lg, ang in oblongos:
        s = s.cut(cq.Workplane("XY").center(x, y).slot2D(ln, lg, ang).extrude(t))
    for r in recortes:
        s = s.cut(r.extrude(t))
    return s


def ret(w, h, cx=0.0, cy=0.0):
    return cq.Workplane("XY").center(cx, cy).rect(w, h)


def ret_arred(w, h, r, cx=0.0, cy=0.0):
    return cq.Workplane("XY").sketch().push([(cx, cy)]).rect(w, h).reset().vertices().fillet(r).finalize()


def furos_anel(r, n, d, ang0=0.0, cx=0.0, cy=0.0):
    return [(cx + r * math.cos(math.radians(ang0 + 360 * i / n)),
             cy + r * math.sin(math.radians(ang0 + 360 * i / n)), d) for i in range(n)]


def casco(pts):
    """Envoltória convexa 2D."""
    pts = sorted(set(pts))

    def giro(o, a, b):
        return (a[0] - o[0]) * (b[1] - o[1]) - (a[1] - o[1]) * (b[0] - o[0])
    inf, sup = [], []
    for p in pts:
        while len(inf) >= 2 and giro(inf[-2], inf[-1], p) <= 0:
            inf.pop()
        inf.append(p)
    for p in reversed(pts):
        while len(sup) >= 2 and giro(sup[-2], sup[-1], p) <= 0:
            sup.pop()
        sup.append(p)
    return inf[:-1] + sup[:-1]


def circulos(lista, n=40):
    out = []
    for cx, cy, r in lista:
        out += [(round(cx + r * math.cos(2 * math.pi * i / n), 3), round(cy + r * math.sin(2 * math.pi * i / n), 3)) for i in range(n)]
    return out


def poly(pts):
    return cq.Workplane("XY").polyline(pts).close()


# ----------------------------------------------------------------------------
# PEÇAS COMPRADAS (aproximações visuais com cotas de catálogo)
# ----------------------------------------------------------------------------
def perfil2020(comp):
    sk = (cq.Sketch().rect(20, 20)
          .push([(0, 9.2), (0, -9.2)]).rect(6.2, 1.6, mode="s")
          .push([(9.2, 0), (-9.2, 0)]).rect(1.6, 6.2, mode="s")
          .push([(0, 6.6), (0, -6.6)]).rect(10, 3.6, mode="s")
          .push([(6.6, 0), (-6.6, 0)]).rect(3.6, 10, mode="s")
          .reset().push([(0, 0)]).circle(2.1, mode="s"))
    return cq.Workplane("XY").placeSketch(sk).extrude(comp)


def nema17(L=48.0, eixo=24.0, d_eixo=5.0):
    """Face de montagem em z=0, corpo para -z, eixo para +z."""
    corpo = cq.Workplane("XY").rect(42.3, 42.3).extrude(-L).edges("|Z").chamfer(4)
    return corpo.union(cyl_z(11, 0, 2)).union(cyl_z(d_eixo / 2, 2, eixo))


def kfl(L, J, Wf, H, flange, bore, d_furo, housing_d):
    fl = (cq.Workplane("XY").slot2D(L, Wf * 0.55, 0).extrude(flange)
          .union(cq.Workplane("XY").circle(Wf / 2).extrude(flange)))
    s = fl.union(cyl_z(housing_d / 2, 0, H))
    s = s.cut(cyl_z(bore / 2, -1, H + 1))
    return s.cut(cq.Workplane("XY").pushPoints([(-J / 2, 0), (J / 2, 0)]).circle(d_furo / 2).extrude(flange))


def kfl001():
    return kfl(63, 48, 38, 16, 5.5, 12, 7, 30)


def kfl08():
    return kfl(48, 37, 27, 11.5, 4.5, 8, 4.5, 21)


def motor_4250():
    """X-mount (costas) em z=0..4, estator, sino até z=54. Eixo invertido: sai pelas costas (z<0)."""
    xm = cq.Workplane("XY").rect(48, 8).extrude(4).union(cq.Workplane("XY").rect(8, 48).extrude(4))
    estator = cyl_z(MOT_D / 2 - 1, 4, 14)
    sino = tube_z(MOT_D / 2, MOT_D / 2 - 3, 14, 4 + MOT_L).union(cyl_z(MOT_D / 2, 4 + MOT_L - 3, 4 + MOT_L))
    eixo = cyl_z(2.5, -22, 4)
    return xm, estator, sino, eixo


def servo_ds3225():
    """Origem no eixo de saída. Eixo ao longo de +x (topo do corpo em x=12); comprimento ao longo de z,
    com o eixo 10 mm à frente do centro; orelhas no plano x = -1..1,5."""
    corpo = box(-28.5, 12, -10, 10, -30, 10)
    orelhas = box(-1, 1.5, -10, 10, -37, 17)
    eixo = cyl_x(3, 12, 18)
    return corpo.union(orelhas).union(eixo)


def bola():
    return cq.Workplane("XY").sphere(BALL_R)


def bateria_makita():
    base = box(-38, 38, -58, 58, 0, 45)
    topo = box(-38, 38, -58, 40, 45, 65).edges("|Y").fillet(6)
    return base, topo


def polia_htd(furo, larg=15.0):
    """Polia HTD 3M 20 dentes, eixo ao longo de Z local, flanges nas pontas."""
    s = cyl_z(POLIA_DP / 2 - 0.4, 0, larg).union(cyl_z(POLIA_DP / 2 + 2.5, 0, 1)).union(cyl_z(POLIA_DP / 2 + 2.5, larg - 1, larg))
    s = s.union(cyl_z(8, larg, larg + 7))
    return s.cut(cyl_z(furo / 2, -1, larg + 8))


def fecho_pressao():
    """Fecho de pressão inox pequeno (trava entre andares): base + alavanca, face de apoio em y=0, corpo para +y;
    o gancho (z > 6) prende no andar de cima."""
    return box(-14, 14, 0, 6, -18, 6).union(box(-10, 10, 4, 12, -14, 2)).union(box(-8, 8, 0, 4, 8, 22))


# ----------------------------------------------------------------------------
# CHAPAS (corte a laser) — geometria local 2D + espessura
# ----------------------------------------------------------------------------
IN_W, IN_D = W - 2 * T_CAR - 2, D - 2 * T_CAR - 2        # placas internas: 312 x 422
R_PLACA = R_CANTO - T_CAR - 1
FUROS_POSTE = [(sx * PX, sy * PY, 5.5) for sx in (-1, 1) for sy in (-1, 1)]
# pinos de centragem (diagonal): na base do lançador, encostados nos postes; no alimentador, atrás das travessas do topo
PINOS = [(sx * (PX - 20), sy * PY, 8.4) for sx, sy in ((1, 1), (-1, -1))]
PINOS_TOPO = [(sx * 90.0, sy * PY, 10.4) for sx, sy in ((1, 1), (-1, -1))]   # pinos-guia presos no canal de cima das travessas
FECHOS_Y = (-120.0, 120.0)
CESTO_BASE = (IN_W - 44, IN_D - 84)                # dobradiças do cesto (no aro, longe dos parafusos dos postes)
X_BATERIA, Y_BATERIA = 46.0, -D / 2 + 72          # centro dos berços das baterias (±x)
Y_PE = D / 2 - 30                                  # pés de borracha (frente)


def ch_piso():
    """Piso do andar de controle."""
    furos = list(FUROS_POSTE)
    for sx in (-1, 1):
        furos += [(sx * X_BATERIA + dx, Y_BATERIA + dy, 4.5) for dx in (-36, 36) for dy in (-55, 55)]   # berços das baterias
        furos += [(sx * 105, Y_PE, 8.5)]                                                                  # pés
        furos += [(sx * 120, D / 2 - 195 + dy, 4.5) for dy in (0, 150)]                                   # caixa IP65
    furos += [(sx * 60, sy * 60, 25) for sx in (-1, 1) for sy in (-1, 1)]                            # alívio
    return chapa(ret_arred(IN_W, IN_D, R_PLACA), T_PISO, furos)


def ch_base_lancador():
    """Base do andar do lançador: lazy susan, passagem de cabos, motor e mancal do fuso do giro."""
    furos = list(FUROS_POSTE) + [(x, y, d) for x, y, d in PINOS]
    furos += [(0, YA, 40)]
    furos += furos_anel(66, 4, 4.5, 45, 0, YA)                     # lazy susan (parte fixa)
    furos += [(PAN_BRACO + dx, Y_MOTOR_GIRO - 10, 4.5) for dx in (-16, 16)]                  # suporte do motor do giro
    furos += [(PAN_BRACO + dx, Y_MANCAL_GIRO, 4.5) for dx in (-16, 16)]                      # mancal da ponta do fuso
    furos += [(sx * 95, sy * 120, 30) for sx in (-1, 1) for sy in (-1, 1)]                    # alívio
    furos += [(-PX + 22, -PY + 40, 22), (PX - 22, -PY + 40, 22)]                               # conectores entre andares
    return chapa(ret_arred(IN_W, IN_D, R_PLACA), T_BASE_LANC, furos)


def ch_alimentador():
    ax, ay = AGIT_C
    furos = list(FUROS_POSTE) + [(x, y, d) for x, y, d in PINOS_TOPO]
    furos += [(0, YA, 76)] + furos_anel(50, 3, 4.5, 30, 0, YA)
    furos += [(ax, ay, 23)] + [(ax + dx, ay + dy, 3.4) for dx in (-15.5, 15.5) for dy in (-15.5, 15.5)]
    furos += [(sx * 120, sy * 150, 4.5) for sx in (-1, 1) for sy in (-1, 1)]                   # rampas
    return chapa(ret_arred(IN_W, IN_D, R_PLACA), T_ALIM, furos)


def ch_aro_topo():
    """Aro do topo do alimentador: assento do cesto."""
    out = ret_arred(IN_W, IN_D, R_PLACA)
    furos = list(FUROS_POSTE) + [(sx * CESTO_BASE[0] / 2, sy * CESTO_BASE[1] / 2, 3.4) for sx in (-1, 1) for sy in (-1, 1)]   # dobradiças (M3)
    return chapa(out, T_ARO, furos, recortes=[ret_arred(IN_W - 60, IN_D - 60, 20)])


def ch_plataforma():
    """Plataforma giratória (referencial do giro, origem no eixo): faixa do garfo e braço do giro (+x)."""
    corpo = (cq.Workplane("XY").circle(78).extrude(T_PLAT).union(box(-81, 81, -34, 34, 0, T_PLAT))
             .intersect(cq.Workplane("XY").circle(84).extrude(T_PLAT)))      # raio máx. 84: passa pelo motor e pelo mancal do giro
    braco = box(70, PAN_BRACO, -14, 14, 0, T_PLAT).union(cyl_z(14, 0, T_PLAT, PAN_BRACO, 0))
    s = corpo.union(braco)
    furos = [(0, 0, 40)] + furos_anel(60, 4, 4.5, 0)
    furos += [(sx * 62, sy * 20, 4.5) for sx in (-1, 1) for sy in (-1, 1)]          # cantoneiras do garfo
    furos += [(PAN_BRACO, 0, 6.2)]                                                    # pino do giro
    for x, y, d in furos:
        s = s.cut(cyl_z(d / 2, -1, T_PLAT + 1, x, y))
    return s


def placa_lateral_pts():
    return casco(circulos([(NIP, WC, 52), (NIP, -WC, 52), (0, 0, 32), (MOT_A[0], MOT_A[1], 30),
                           (MOT_B[0], MOT_B[1], 30), (-50, -88, 30)], 36))


ESPACADORES = [(-62, 45), (130, 60), (130, -60), (0, -122)]


def furos_motor(mu, mv, alvo):
    """Furo do eixo + 4 oblongos M3 na direção da correia (tensionamento ±3 mm)."""
    ang = math.degrees(math.atan2(alvo[1] - mv, alvo[0] - mu))
    furos = [(mu, mv, 14)]
    obl = []
    for a in (45, 135, 225, 315):
        r = 19.0
        obl.append((mu + r * math.cos(math.radians(a)), mv + r * math.sin(math.radians(a)), 9.4, 3.4, ang))
    return furos, obl


def bossas_carenagem_roda(lado):
    """Pontos (u, v) dos tubos de fixação da carenagem da roda (lado +1: roda de cima)."""
    cv = WC * lado
    return [(NIP + 81.5 * math.cos(math.radians(a)), cv + 81.5 * math.sin(math.radians(a)))
            for a in ((180, 160) if lado > 0 else (180, 200))]


def bossas_tampa(lado):
    """Pontos (u, v) dos espaçadores da tampa da correia: dentro do laço da correia, longe das polias."""
    m = MOT_A if lado > 0 else MOT_B
    r = (NIP, WC if lado > 0 else -WC)
    return [(m[0] + t * (r[0] - m[0]), m[1] + t * (r[1] - m[1])) for t in (0.35, 0.65)]


SERVO_EIXO = (-45.0, -82.0)     # eixo do servo do empurrador (u, v)


def ch_lateral():
    """Placa lateral da cabeça (u=frente, v=cima, origem no pivô). A mesma peça nos dois lados."""
    furos = [(0, 0, 8.1),
             (NIP, WC, 16), (NIP, WC - 24, 7), (NIP, WC + 24, 7)]
    furos += [(u, v, 5.5) for u, v in ESPACADORES]
    fa, oa = furos_motor(*MOT_A, (NIP, WC))
    fb, ob = furos_motor(*MOT_B, (NIP, -WC))
    furos += fa + fb
    furos += [(-64, -70, 4.5), (-64, -108, 4.5)]                   # suporte do servo (placa -x)
    furos += [(-25, -44, 4.5), (25, -44, 4.5)]                     # berço
    furos += [(-30, 40, 4.5), (60, 40, 4.5)]                       # funil
    furos += [(125, -42, 4.5)]                                     # suporte dos trilhos
    furos += [(u, v, 4.5) for lado in (1, -1) for u, v in bossas_carenagem_roda(lado)]   # carenagens das rodas
    furos += [(NIP - 24, WC, 3.4), (NIP - 24, -WC, 3.4)]           # suportes dos sensores Hall
    furos += [(u, v, 3.4) for lado in (1, -1) for u, v in bossas_tampa(lado)]            # tampas das correias
    obl = oa + ob + [(NIP, -WC, 24, 16, 90), (NIP, -WC - 24, 15, 7, 90), (NIP, -WC + 24, 15, 7, 90)]
    return chapa(poly(placa_lateral_pts()), PL_T, furos, obl)


def ch_garfo():
    """Garfo do tilt (plano y-z local: x=u, y=altura acima da plataforma)."""
    h = ZP - Z_PLAT        # 205
    pts = casco(circulos([(0, h, 30), (-26, 4, 4), (26, 4, 4)], 40)) + [(-30, 0), (30, 0)]
    s = poly(casco(pts)).extrude(YOKE_T)
    for x, y, d in [(0, h, 12), (0, h - 18.5, 4.5), (0, h + 18.5, 4.5), (-18, 22, 4.5), (18, 22, 4.5), (0, 110, 30)]:
        s = s.cut(cyl_z(d / 2, -1, YOKE_T + 1, x, y))
    return s


def ch_manivela():
    """Manivela presa no semi-eixo -x por furo em D (eixo Ø8 com chato de 7 mm); o pino da ponta entra na porca do tilt."""
    pts = casco(circulos([(0, 0, 14), (MANIVELA[0], MANIVELA[1], 11)], 30))
    s = chapa(poly(pts), 6.0, [(MANIVELA[0], MANIVELA[1], 5.5)])
    d = cq.Workplane("XY").circle(4.05).extrude(6).intersect(cq.Workplane("XY").center(-0.5, 0).rect(7.1, 9).extrude(6))
    return s.cut(d)


def furo_d(t):
    """Furo em D para eixo Ø12 com chato (11,1 mm entre faces)."""
    return (cq.Workplane("XY").circle(6.05).extrude(t)
            .intersect(cq.Workplane("XY").center(-0.5, 0).rect(11.1, 13).extrude(t)))


def ch_disco_inercia():
    s = cq.Workplane("XY").circle(60).extrude(3)
    s = s.cut(cq.Workplane("XY").pushPoints([(x, y) for x, y, _ in furos_anel(50, 6, 4.5, 0)]).circle(2.25).extrude(3))
    return s.cut(furo_d(3))
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

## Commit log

2026-10-06 Página de apresentação e arquivos do lançador de bolas de tênis
    Landing page com modelo 3D interativo, imagens, memorial do projeto em
    seções recolhíveis e arquivos de fabricação (STEP, STL, DXF, PDF, CSV)
    gerados pelo modelo paramétrico em CadQuery.
    Claude-Session: https://claude.ai/code/session_013zuQ77tuQX79oDgJ7kzY9Y
    [abracadeira_alca.step, abracadeira_alca.stl, anel_articulacao.step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]
2026-10-06 Simulação na quadra, zoom suave e memorial em Markdown
    - Aba Quadra: máquina na linha de saque ou de fundo, trajetória com arrasto
    e Magnus, rede, 1º e 2º quique, mira por toque e mapa de alcance
    - Zoom proporcional ao gesto (roda e trackpad) e botões + / −
    - PROJETO.md: memorial técnico sem preços e sem próximos passos, com
    botão para ler, copiar e baixar na página
    - Seção 3.5 do memorial com o modelo de trajetória e a tabela de alcance
    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
2026-10-07 Trajetória da simulação em ciano, para não confundir com a bola
    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
2026-10-07 Versão 2: máquina compacta em três andares, carenagem com e sem, vento na quadra
    - Modelo novo: andares de controle, lançador e alimentador empilhados com pinos e fechos;
    giro ±12,5° por fuso, inclinação 0–30° por fuso Tr8×2 e manivela, rodas por correia HTD,
    cesto de tela dobrável, painel traseiro com tela e emergência, semáforo e duas antenas.
    - Arquivos de fabricação refeitos: 10 DXF + pranchas, 41 STL/STEP, eixos, montagem STEP
    com e sem carenagem e carenagem só em STEP (material a definir).
    - verificar.py confere 18 posições, o caminho da bola e todas as peças entre si.
    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
    [abracadeira_alca.step, abracadeira_alca.stl, abracadeira_alca_espelhada.step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]
2026-10-13 MVP de bancada: base do lançador, giro, inclinação e cabeça
    Branch só com o que entra no MVP alimentado por fonte de bancada:
    peças para imprimir, cortar e usinar, lista unificada de compras,
    esquemas da elétrica, placa de controle, cabos com comprimentos,
    simulação no Wokwi, firmware com comandos pela serial e passo a
    passo de montagem. Tudo é peça da máquina completa.
    Correções do CAD que valem para a máquina toda: pivô do tilt com
    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
